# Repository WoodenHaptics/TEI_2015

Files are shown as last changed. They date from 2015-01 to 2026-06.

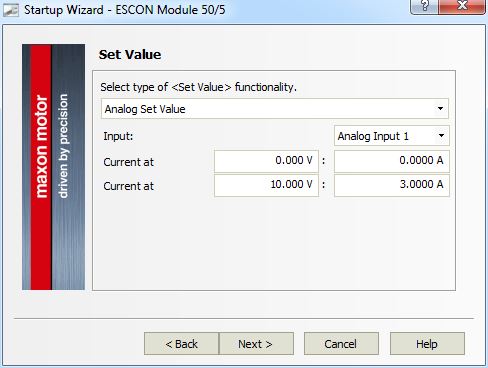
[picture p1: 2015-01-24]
Electronics/Escon-config/07.JPG

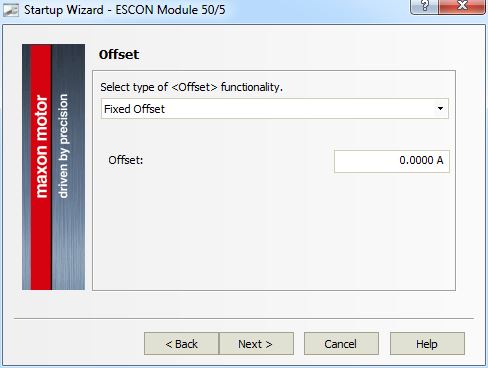
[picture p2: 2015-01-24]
Electronics/Escon-config/08.JPG

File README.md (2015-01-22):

# TEI_2015

Welcome! On this repository you will find the information you need to start fabricating your own grounded spatial haptic device based on our default open source design. This site is essentially the companion to our TEI2015 conference paper WoodenHaptics: A Starting Kit for Crafting Force-Reflecting Spatial Haptic Devices. We hope you want to share our joy of crafting haptic devices!

more information on this device and its construction in our website:
www.woodenhaptics.org

Please start with reading the website and the research paper found on the website.

The license for this whole project is CC-BY-SA 4.0 if nothing else mentioned. 
The CHAI3D extension software is BSD-licensed like its parent project. 
Are you interesed in other licensing agreements or like to distribute the kit, email jofo02 at kth.se

/ Jonas, Mike and Jordi - January 17th 2015

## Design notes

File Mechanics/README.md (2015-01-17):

  This is the source drawings for the default design of the WoodenHaptics starting kit. 
  You have to have SolidWorks to edit the files, but you also have exported drawings/cutout sheets
  for laser-cutting in the lasercut_drawings/ folder. 

  /Jonas Forsslund Jan 17th 2015

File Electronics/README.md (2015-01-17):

# Main_board_EAGLE_v_0_1

Eagle files for the main board version 0.1

This is the first version of the wooden haptics driver. This bord will accept 3 motors up to 3Amps each and 3 decoders. It has been designed to host ESCON motor drivers:

http://www.maxonmotor.com/maxon/view/product/control/4-Q-Servokontroller/438725

The same ESCON sockets can be used to connect any other DC motor driver if conencting to the propper pin connectors (PWR, motor out and PWM)

THis board can be used with and external DAQ (using the extension board) board or a mBed M3 Cortex:

https://www.sparkfun.com/products/9564

The elctronics are powerd up over USB but in order to power the motors it requires an external power supply 12v-48v, depending on the motors used.

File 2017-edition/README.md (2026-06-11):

# WoodenHaptics — 2017 Edition (notes & version history after 2015)

**Status: never formally released.** The original public release is the *Version 1.0 — TEI 2015 Edition* (Maxon RE40 motors). During 2016–2017 the kit was revised toward smaller motors and a few other improvements, but the changes were never compiled into a packaged release. This folder is a retroactive attempt to gather what exists so a proper "2017 Edition" can be assembled.

Dates below were verified from the embedded file metadata (Adobe XMP `CreateDate`/`ModifyDate`), the two bills of materials, and the 17 Jan 2017 mailing-list announcement (quoted below). Items marked *(recollection)* are from memory and should be double-checked before release.

---

## Timeline

| When | What | Source |
|---|---|---|
| Jan–Jun 2015 | **Version 1.0 (TEI 2015 Edition).** SolidWorks CAD (`Mechanics/`), DXF export (`lasercut_drawings/dxf/`), Illustrator laser files, BOM v1.0. Motor: **Maxon RE40 (Ø40 mm, 148877)**. | repo, `lasercut_drawings/README.md` (Jan 5 2015), BOM v1.0 |
| 2015-06 / 2015-10 | Illustrator laser sheets prepared from the DXFs on cutlasercut.com templates and verified for cutting. `body_a` last tweaked Oct 2015. | XMP dates, `illustrator/README.md` (Jun 2 2016) |
| **2016-10-07** | Laser-cut order: the four `Birch_Plywood_6mm_600mmx600mm_*_updated.ai` sheets **plus a separate `kirimoto-inkskape-body-c-a4.svg`** (an Inkscape A4 sheet for an experimental new *body c* / arm). *(order record)* | order info |
| **2017-01-17** | Mailing-list announcement of the updated kit (full text below): red ball handle, **smaller 30 mm motors (Maxon RE30)**, 19.5 V supply (laptop chargers), beta USB, new *body c* on Onshape, PCB v0.4, assembly videos. | email |
| **2017-05-09** | New arm brought into Illustrator: `new_body_c.ai` (exported via a **Mac**) and the combined `…body_b_and_c_updated_2017.ai/.pdf` (the lighter arm — larger triangular lightening cut-outs). | XMP dates |
| **2017-05-11** | Re-nested onto 500 × 450 mm sheets: `500x450_6mm_4_och_en_halv_skivor.ai` (+ `_uppdaterad.pdf`). | XMP dates |
| **2017-05-15** | **`Birch_Plywood_6mm_A2_four_sheets.pdf`** — final re-nest onto four A2 sheets; this is the file that was **actually ordered / cut** on this date. BOM **v1.1 "with 30 mm motors and USB"**. | XMP dates, order info, BOM v1.1 |

---

## What changed vs. the 2015 (RE40) edition

### Mechanics — RE40 → RE30
The structural design did **not** change. Verified findings:

- **Motor mount is shared.** The motor bolts to the wood with **M3 screws on a Ø22 bolt circle**, and **both RE40 and RE30 use that pattern** — so no plate needed to be re-drawn. (BOM v1.0 already lists 40 / 30 / 25 mm Maxon motors as interchangeable alternatives with the same `M3x10` screws.) The `base` / `body_a` / `body_b` laser geometry is unchanged 2015 geometry.
- **Only the arm (`body c`) was re-drawn**, to lighten it (lower inertia for the smaller motors) — `new_body_c.ai` / `…body_b_and_c_updated_2017`.

The practical RE40 → RE30 conversion is therefore just:

1. **Coupler:** `CPL25-6-10` → **`CPL12-4-5`** (RE30 has a 5 mm shaft; the new coupler is also shorter).
2. **Remove one wooden lamination** from the motor-holder stack to take up the shorter coupler/motor length. *(recollection — the motor holder is a laminated plate stack; using one layer fewer of an existing part, no new geometry.)*
3. **Motor:** `148877` (40 mm) → **`310009`** (30 mm), with 500 CPR encoder.
4. Use the **lightened arm** (`body c`).

### Electronics / system (from the 2017 announcement)
- **Red ball handle** (kitchen-drawer knob) for clearer affordance.
- **19.5 V** supply so a standard laptop charger works (e.g. Innergie PowerGear 90) — replaces the 48 V supply.
- **USB support** (beta at the time).
- **PCB v0.4.**
- Code on the `experimental` branch of the GitHub repo; assembly videos at <http://woodenhaptics.org/build.html>.

---

## Contents of this folder

```
2017-edition/
├── README.md                     ← this file
├── bom/
│   └── WoodenHaptics Bill of Materials - 2017 Edition (Ver 1.1 with 30mm motors and USB).csv
└── lasercut/
    ├── Birch_Plywood_6mm_A2_four_sheets.pdf                         ← THE production cut file (A2 ×4, 15 May 2017)
    ├── new_body_c.ai                                                ← lightened arm, exported from Onshape (Mac)
    ├── Birch Plywood_6mm_600mmx600mm_body_b_and_c_updated_2017.ai   ← combined new-arm sheet (600×600 master)
    ├── Birch Plywood_6mm_600mmx600mm_body_b_and_c_updated_2017.pdf
    ├── 500x450_6mm_4_och_en_halv_skivor.ai / _uppdaterad.pdf        ← intermediate 500×450 re-nest (11 May 2017)
    ├── Birch Plywood_6mm_600mmx600mm_base_1_of_2_updated.pdf        ← unchanged 2015 geometry (RE40 = RE30)
    ├── Birch Plywood_6mm_600mmx600mm_base_2_of_2_updated.pdf        ← unchanged 2015 geometry
    └── Birch Plywood_6mm_600mmx600mm_body_a_updated.pdf             ← unchanged 2015 geometry
```

All sheets: **6 mm birch plywood**, red (RGB 255,0,0) = cut-through, black = engrave ~1.5–2.5 mm (same conventions as `Mechanics/lasercut_drawings/`).

**If you only cut one thing, cut `Birch_Plywood_6mm_A2_four_sheets.pdf`** — it is the complete, as-built four-sheet layout (incl. the lightened arm), sized for an A2 (594 × 420 mm) laser bed.

---

## Provenance & gaps (important before a release)

- **The parametric CAD for the new arm is NOT in this repo.** It was authored in **Onshape**:
  <https://cad.onshape.com/documents/3a7c6140b3b524fe2e399f10/w/c1ea1269244ce72f85bc9402/e/6f0b243d8c0c198195d363ae>
  Locally the arm survives only as **flat laser vectors** (`new_body_c.ai`, and inside the A2 PDF). The original Inkscape source `kirimoto-inkskape-body-c-a4.svg` could not be found on any local disk.
- The RE40 parametric CAD is complete in `../Mechanics/` (SolidWorks). To make the RE30 arm editable again, either re-export from Onshape, or trace/convert `new_body_c.ai` → DXF/SVG and re-integrate.
- These 2017 laser files previously lived only in a loose `Woody-May-2017` working folder, not under version control — copied here so they are not lost.

## TODO toward a packaged 2017 Edition
- [ ] Recover or re-create editable arm CAD (Onshape export, or convert `new_body_c.ai`).
- [ ] Confirm the "remove one lamination" step and document the motor-holder stack-up for RE30 (drawing or photo).
- [ ] Add the RE30 coupler (`CPL12-4-5`) and red ball handle to a parts drawing / BOM cross-check.
- [ ] Capture the electronics changes (PCB v0.4, 19.5 V, USB) from the `experimental` branch into this edition.
- [ ] Decide whether this supersedes or sits alongside the TEI 2015 Edition, and tag a release.

---

### Appendix — 17 Jan 2017 mailing-list announcement (verbatim)

> I have been working on updating woodenhaptics kit in an attempt to make it more complete and slightly reduce cost. I propose the following changes:
> * Red ball handle (kitchen drawer knob) improves affordance i.e. makes it clear where to hold
> * Smaller motors (30 mm, Maxon RE30) are cheaper and lighter which lowers inertia.
> * Switching to 19.5V power supply so we can use standard laptop chargers, I have successfully used the Innergie Powergear 90
> * USB support working (but still beta)
>
> CAD models for new body c (arm) can be found on onshape (the collaborative, free-to-use cad software I use now)
> https://cad.onshape.com/documents/3a7c6140b3b524fe2e399f10/w/c1ea1269244ce72f85bc9402/e/6f0b243d8c0c198195d363ae
>
> Code for mbed and computer side is shared on the experimental-branch of the github. […] Updated PCB:s are also there (version 0.4).
>
> I have also made some assembly instruction videos covering the whole process […] http://woodenhaptics.org/build.html
>
> Jonas

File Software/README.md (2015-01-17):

<pre>
WoodenHaptics extension to Chai3D 3.0.0
   
Written by Jonas Forsslund, KTH, 2014-12-08

Chai3D is a minimalistic API for haptic applications. Website is www.chai3d.org
but the latest and greatest is found on cs277.stanford.edu. You need 
that EXACT version for this patch to work:

http://web.stanford.edu/class/cs277/resources/downloads/chai3d-3.0.0-Makefiles.tar.gz
(59930012 bytes))

Unzip the contents of our zip-file's subfolder into your Chai3D folder
   
then run "make". 

It will overwrite these files:

    Makefile.common.lin

    CHapticDeviceHandler.cpp
    CGenericHapticDevice.h

Note: To make sense of this you (currently) need to have a
Sensoray S826 DAQ PCIe card in your computer. You
also need to install the kernel module for that card.

That driver is provided as source in /external/s826

please read the readme.txt in that folder for instructions.

This patch is licensed under: BSD

Good luck and have fun!
   /Jonas (jofo02@kth.se)

</pre>

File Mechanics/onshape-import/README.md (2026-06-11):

# Onshape import bundle + verification

Artifacts for importing the SolidWorks `Mechanics/` model into
[Onshape](https://cad.onshape.com), and screenshots confirming it worked.

## `woodenhaptics.zip`
A **flat** archive of every SolidWorks part/assembly in `Mechanics/`
(`.SLDPRT` / `.SLDASM` / `.SLDDRW`), **excluding** `lasercut_drawings/`.

Onshape's SolidWorks importer requires that the zip contain **no folders** and
that its **filename matches the root assembly** — here `woodenhaptics.SLDASM`.
Regenerate from `Mechanics/` with:

```sh
cd Mechanics
find . -path ./lasercut_drawings -prune -o \
  -type f \( -name '*.SLDPRT' -o -name '*.SLDASM' -o -name '*.SLDDRW' \) -print |
  while read f; do zip -jq ../woodenhaptics.zip "$f"; done
```

(108 files; the part/assembly basenames are unique, so flattening is collision-free.)

## `screenshots/`
The bundle imported cleanly into Onshape. Each shot highlights one subassembly
(yellow) — this is also the rigid-body breakdown used by the FreeCAD migration
(`../../freecad-migration-plan.md`):

| File | Shows |
|---|---|
| `tei2015-woody.png` | full assembly (import tree on the left) |
| `tei2015-woody-base.png` | `base` — fixed to world (frame N) |
| `tei2015-woody-a.png` | `body_a` — θa, rotates on base |
| `tei2015-woody-b.png` | `body_b` — θb |
| `tei2015-woody-c.png` | `body_c` — driven by the four-bar |
| `tei2015-woody-c-prim.png` | `body_c_prim` — θc, the parallelogram link |

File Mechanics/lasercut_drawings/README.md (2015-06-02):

  Please note the following for laser-cutting the parts.

  - All sheets are 6 mm, preferably birch plywood
  - The source drawing(s) in .SLDDRW for each body is found in respective part's folder
  - These files are exported to .dxf files in the lasercut_drawing/dxf/ folder
  - If you alter the parts of a body, the .DWG will be updated when you load them, but
    not necessarily any exported files. So make sure to do the export (save as...) as well.
  
  - You can use the dxf directly if:
    * Your laser-cutter can handle up to A2 sheets (594 x 420 mm)
    * You make sure the laser-cutter cuts in the middle of the lines, or change
      the thickness to be as thin as is required to do so (for VLS-4.60 you set it to ~0.001 mm)
    * The BLACK AREAS should be ENGRAVED to 1.5-2.5 mm, instead of cut. Be careful to 
      set the edges of those areas to be cut through OR not cut through depending on location.
  
  - Otherwise, we reccommend:
    * Using Adobe Illustrator; "place" the .DXF file(s) on a sheet suitable for your cutter.
    * You may have to place with scaling 1:1000 or 1000:1, make sure it NEVER scales to "fit"
    * Always measure an object to see it is exactly as expected
    * Change lines to be as thin as necessary (0.001 mm/pt in our case)
    * Change line colors to be what you code as "cut through" (RGB: 255,0,0 in our case)
    * Change black areas to be coded as "engraving" (see above, in our case fill with RGB: 0,0,0)

  /Jonas Forsslund Jan 5th 2015

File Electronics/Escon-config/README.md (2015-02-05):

This is screenshots from the step-by-step configuration guide in
ESCON Studio that you find under "Download" on this page:
http://www.maxonmotor.com/maxon/view/product/control/4-Q-Servokontroller/438725

Alternatively, you can "download" the config-file.edc to the escon using ESCON Studio.

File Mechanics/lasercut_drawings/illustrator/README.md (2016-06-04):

  Please note the following for laser-cutting the parts.

  These files are prepared using the cutlasercut.com template .ai files 
  and then by "place" the .dxf files after scaling (see image
  import-from-dxf-settings.png for how this is done). 

  These updated files are tested for cutting by cutlasercut.com 
  just tell them to use 6.0 mm (or slightly less) plywood and cut
  as straight down as possible.

  /Jonas Forsslund June 2nd 2016

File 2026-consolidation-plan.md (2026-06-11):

# WoodenHaptics — 2026 Consolidation Plan

A handoff/planning doc for gathering everything WoodenHaptics into a single,
canonical 2026 repository. Written so the work can be picked up from any
computer — **everything referenced here is committed and pushed; the local
working copy can be dropped.**

Status: **draft / basis for discussion.** The big open decision (which GitHub
home) is deliberately left open — see "Open decision" below.

---

## Why consolidate
The project's material is currently scattered across several repos and editions
with overlapping, partly-stale content. The paper explicitly invites the
community to build on the kit; a single front-door repo, framed from a 2026
perspective, makes that realistic. The goal is **one repo** that holds the
2015 reference design, the never-released 2017 revision, the electronics/
software, and the forward-looking FreeCAD model — clearly separated by edition,
with a top-level README that orients a newcomer.

---

## Current GitHub landscape (verified 2026-05-19)

| Repo | State | Holds | Verdict |
|---|---|---|---|
| **`WoodenHaptics/TEI_2015`** (this repo) | active, pushed today | SolidWorks `Mechanics/`, lasercut DXF/AI, BOM v1.0, the TEI 2015 paper PDF, `2017-edition/`, `freecad-migration-plan.md`, Electronics/Software/Docs | richest mechanical source; **best basis** |
| **`WoodenHaptics/woody-experimental`** | 2019, "do not use" | PCB **v0.4** (`woodenHaptics_v_0_4.brd/.sch`), `mbed-code`, `chai3d-3.0.0-woody`, `daq-direct`, `websim`, `woodenhaptics_2016ed.json`, `woodenhaptics_aluhaptics_2017-03-16.json` | **valuable** — this is the 2016/2017 electronics + code the 2017 README points to |
| **`forsslund/WoodenHaptics`** | **fork** of MobileLifeCentre, pushed **Dec 2014** | `woodenHaptics_v_0_1`, `Sensoray_DAQ`, `DAQ_Extension_Board_December`, `woddenHaptics_Egle_files` | historical v0.1 only; it's a stale fork → poor base |
| **`MobileLifeCentre/WoodenHaptics`** | upstream original, Jan 2015 | the true origin of the fork above | historical root |

**Implication:** the substance lives in `TEI_2015` (mechanics + 2017 edition)
and `woody-experimental` (electronics + code). The personal/MobileLife repos are
mostly historical v0.1 material.

---

## Open decision — which GitHub home

Three options, with trade-offs:

1. **New repo `WoodenHaptics/woodenhaptics` (org, lowercase) — recommended.**
   Clean canonical name, lives in the org so multiple maintainers and the
   `woodenhaptics.org` identity align, and no awkward fork relationship. Pull
   `TEI_2015` and `woody-experimental` content in under `editions/` and
   `electronics/`+`software/`; then **archive** the old repos with a README
   pointer. Most work, cleanest result.

2. **Continue from `forsslund/WoodenHaptics`.** It already exists and is
   personally owned, but it's a **2014 fork of MobileLifeCentre** containing only
   v0.1-era files — the fork lineage and stale content make it a weak base. Would
   need a heavy rewrite anyway. Not recommended unless you specifically want it
   under your personal account rather than the org.

3. **Keep building inside `WoodenHaptics/TEI_2015` and rename it.** Lowest
   effort — it's already the richest repo. But the name `TEI_2015` is tied to the
   paper/citation; renaming it muddies that link, and a rename leaves redirect
   baggage. Better to keep `TEI_2015` as the frozen, citable 2015 artifact.

**Recommendation:** option 1. Keep `TEI_2015` frozen as the paper's citable
snapshot; make a fresh org repo the living home. Decide org-vs-personal
(`WoodenHaptics/` vs `forsslund/`) as a governance question — the org is the
better long-term community home, but that's yours to call.

---

## Proposed structure for the new repo

```
woodenhaptics/
├── README.md                 ← 2026 framing: what it is, editions, how to start, links to paper & woodenhaptics.org
├── LICENSE.md                ← carry over (open-source/open-hardware)
├── paper/
│   └── woodenhaptics-tei-2015-paper.pdf
├── editions/
│   ├── tei-2015/             ← from TEI_2015: Mechanics/ (SolidWorks), lasercut DXF/AI, BOM v1.0
│   │   └── README.md         ← "the citable reference design; RE40 motors"
│   └── 2017/                 ← from TEI_2015/2017-edition: RE30 lasercut, BOM v1.1, the detailed timeline README
├── cad-freecad/              ← output of freecad-migration-plan.md (articulated open-source model)
├── electronics/              ← from woody-experimental: PCB v0.4 (.brd/.sch), DAQ boards
├── software/                 ← from woody-experimental: mbed-code, chai3d-3.0.0-woody, daq-direct, websim, config JSONs
├── docs/                     ← assembly notes, build videos pointer (woodenhaptics.org/build.html)
└── archive/                  ← optional: v0.1-era material from forsslund/MobileLifeCentre if worth preserving
```

Principles:
- **Editions are folders, never branches** (additive snapshots, never merged).
- One top-level README is the front door; each edition keeps its own README
  (the 2017 one is already excellent and self-documenting).
- Bring CAD source where it exists; where it doesn't (the 2017 arm, which is
  Onshape-only — see `2017-edition/README.md`), keep the link + flat vectors and
  flag the gap.

---

## Migration checklist

- [ ] **Decide the GitHub home** (open decision above).
- [ ] Create the new repo + `README.md` skeleton with the structure above.
- [ ] Import `TEI_2015` mechanical content → `editions/tei-2015/` (preserve history
      via `git subtree`/`filter-repo` if history matters, else a clean copy).
- [ ] Move `2017-edition/` → `editions/2017/`.
- [ ] Import `woody-experimental` electronics → `electronics/`, code → `software/`.
- [ ] Run the FreeCAD migration (`freecad-migration-plan.md`) → `cad-freecad/`.
- [ ] Triage `forsslund/WoodenHaptics` + `MobileLifeCentre` v0.1 → `archive/` or drop.
- [ ] Write the 2026 front-door README (framing, editions table, getting-started,
      links to paper + woodenhaptics.org).
- [ ] **Archive** `TEI_2015` and `woody-experimental` on GitHub with a README
      pointer to the new repo (keep them — `TEI_2015` is the paper's citation target).
- [ ] Cross-check BOMs (RE40 v1.0 vs RE30 v1.1) and reconcile the open TODOs in
      `2017-edition/README.md` (editable arm CAD, motor-holder lamination, coupler,
      handle, electronics changes).

---

## Local working copy — what's here and what's safe to drop

After the commits accompanying this plan, **everything important is in git and
pushed.** This local checkout can be deleted.

- **Committed & pushed:** all of `2017-edition/`, `freecad-migration-plan.md`,
  the paper PDF, this plan, the Onshape import bundle + verification screenshots
  (`Mechanics/onshape-import/`), and the existing repo contents.
- **Removed (byte-identical duplicates):** two root CSVs — copies already live in
  the repo (TEI-2015 BOM at repo root, 2017 BOM under `2017-edition/bom/`).
- **External, not in any repo — don't lose:** the 2017 arm parametric CAD lives
  only on Onshape (link in `2017-edition/README.md`); the original Inkscape source
  `kirimoto-inkskape-body-c-a4.svg` is already missing.

---

## Related docs
- `freecad-migration-plan.md` — the articulated open-source CAD effort that feeds
  `cad-freecad/` in the new repo.
- `2017-edition/README.md` — detailed, source-verified timeline and provenance of
  the 2017 revision, plus its own TODO toward a packaged release.

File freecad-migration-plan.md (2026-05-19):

# WoodenHaptics → FreeCAD Migration Plan

## Goal
Publish an articulated FreeCAD model of the reference design so the community can open, inspect, and modify the device without proprietary software. End-effector point P can be moved by dragging; the RRR linkage and the C/C' four-bar respond correctly.

## Scope
**In:** Geometry of all parts, subassembly grouping, three revolute DOFs (θa, θb, θc), parallelogram closure, gravity-correct orientation.
**Out:** Motor→body cable ratios, cable rope geometry as a kinematic element, lasercut drawings, electronics box, software/firmware, FEA.

## Subassembly mapping
Each Mechanics/ subfolder becomes one FreeCAD document. Parts inside are rigidly fixed (no internal joints — treat each subassembly as one solid body).

| Folder | FreeCAD file | Role |
|---|---|---|
| `base/` | `base.FCStd` | Fixed to world (frame N) |
| `body_a/` | `body_a.FCStd` | Rotates θa about vertical axis on base |
| `body_b/` | `body_b.FCStd` | Rotates θb about horizontal axis on body_a |
| `body_c_prim/` | `body_c_prim.FCStd` | Rotates θc about horizontal axis on body_a |
| `body_c/` | `body_c.FCStd` | Driven via four-bar (parallel to body_b) |
| `other/` (RE40) | reuse as needed | Visual only, place inside relevant subassembly |
| top level | `woodenhaptics.FCStd` | Links the five subassemblies + joints |

## Migration steps

**1. Export from Onshape (one-time)**
Once the Onshape import lands (using the zip we built), export each subassembly separately as STEP AP242:
- `base.step`, `body_a.step`, `body_b.step`, `body_c.step`, `body_c_prim.step`
- Plus `woodenhaptics_full.step` as a sanity reference for poses.

**2. Build subassembly documents**
For each STEP:
- Open in FreeCAD → save as `.FCStd`
- Verify it imports as a single Compound or as a set of solids in their assembled positions
- If multiple solids: group under one `App::Part` container so the whole subassembly behaves as one rigid body in the top-level assembly
- No internal joints needed

**3. Build top-level assembly (`woodenhaptics.FCStd`)**
- New document, Assembly workbench
- Insert each subassembly as a linked document (File → Link)
- Ground `base` (fixed joint to origin)
- Add joints (see below)

**4. Define joints**

| Joint | Type | Between | Axis |
|---|---|---|---|
| J1 (θa) | Revolute | base ↔ body_a | Vertical (Z in N frame) through the body_a turntable center |
| J2 (θb) | Revolute | body_a ↔ body_b | Horizontal, through body_b's shaft bearings on body_a |
| J3 (θc) | Revolute | body_a ↔ body_c_prim | Horizontal, parallel to J2, through body_c_prim's shaft |
| J4 | Revolute | body_b ↔ body_c | Horizontal, at the far end of body_b |
| J5 | Revolute | body_c_prim ↔ body_c | Horizontal, at the far end of body_c_prim (closes the four-bar) |

J4 + J5 close the loop. The OndselSolver should resolve this as a single DOF along θc once θa and θb are fixed. If it struggles to converge, pin θc as the driver on J3 and let J5 float (or vice versa) — pick whichever solves cleanly.

**5. Verify articulation**
- Drag body_a around vertical axis → whole arm sweeps (θa works)
- Drag body_b → body_c stays parallel to it as the four-bar pivots (θb works, parallelogram correct)
- Drag body_c_prim → body_c translates parallel to body_b (θc works)
- Confirm end-point P traces a workspace consistent with eq. (1) in the paper

**6. Polish for publication**
- Set materials/colors (plywood color on structural parts, dark on motors/bearings)
- Add a simple `README.md` explaining the joint structure and noting what is *not* modelled (cable ratios)
- Save with FreeCAD 1.0+ format; document the minimum FreeCAD version in README

## Deliverables
- `freecad/` directory in the repo with the six `.FCStd` files
- `freecad/README.md` covering versions, how to open, known limitations
- An exported `woodenhaptics_articulated.step` for users who want to consume it in other tools

## Risks / open questions
- **Four-bar convergence**: if OndselSolver chokes on the closed loop, fallback is to omit J5 and just animate body_c manually parallel to body_b via a single expression (`body_c.Placement = body_b.Placement` with offset). Less elegant but visually identical.
- **STEP per-subassembly vs. one big STEP**: exporting subassemblies separately preserves the grouping we want; exporting one big STEP and re-splitting in FreeCAD is more work. Go with separate exports if Onshape allows it cleanly.
- **Motor placement**: paper says motors B and C mount on body_a. If they're geometrically inside `body_a/` already in your SLDASM, no extra work. If they live in `other/`, decide which subassembly they belong to before exporting.

## Suggested order of work
1. Get the Onshape import working (already in motion)
2. Export the five subassembly STEPs
3. Build `base.FCStd` and `body_a.FCStd`, prove J1 works in a minimal two-body assembly
4. Add body_b + J2, verify
5. Add body_c_prim + J3
6. Close the loop with body_c + J4 + J5
7. Polish, write README, commit

Roughly a half-day of focused work if the STEP imports cleanly; a full day if the four-bar needs coaxing.

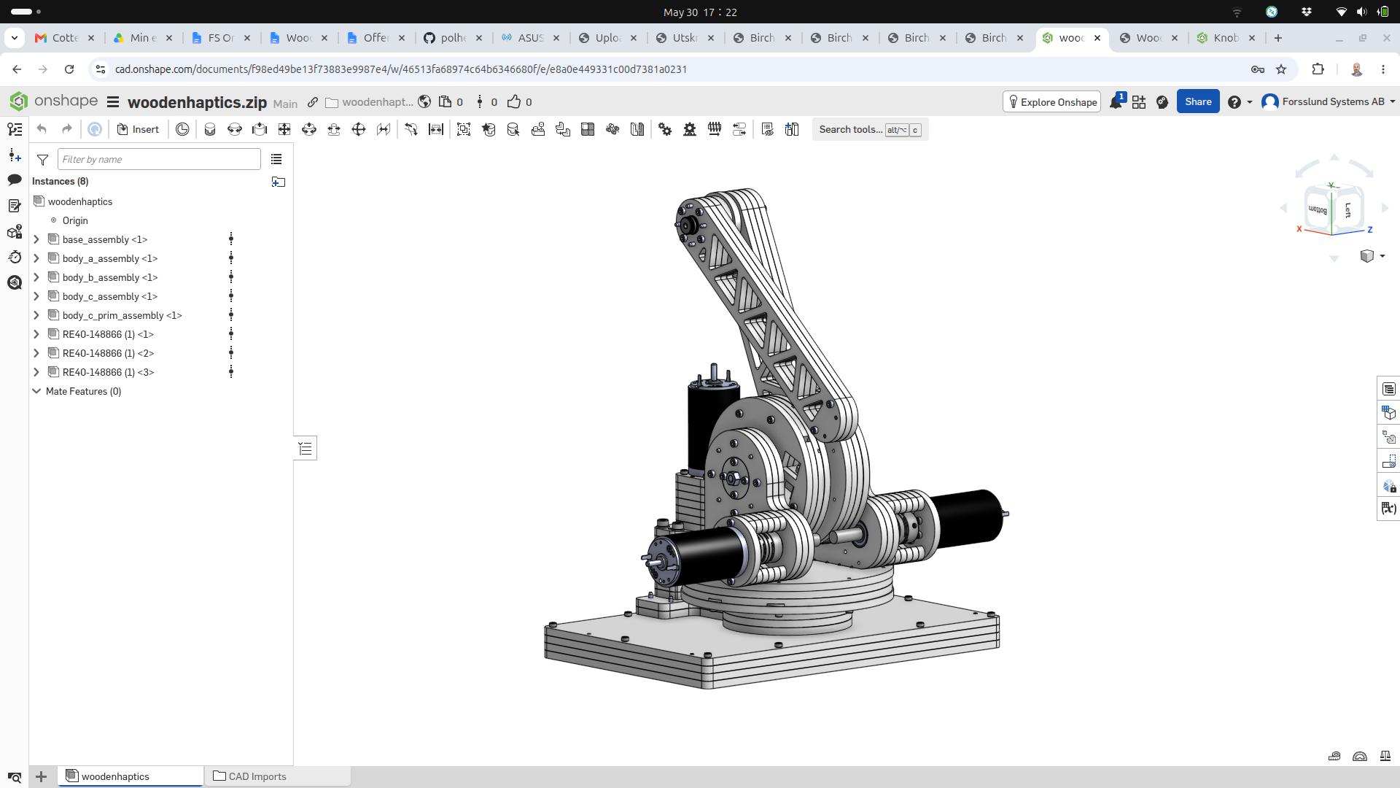
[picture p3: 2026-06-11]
Mechanics/onshape-import/screenshots/tei2015-woody.png

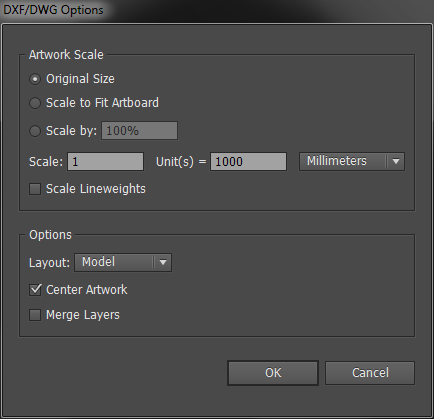
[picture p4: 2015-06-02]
Mechanics/lasercut_drawings/illustrator/import-from-dxf-settings.png

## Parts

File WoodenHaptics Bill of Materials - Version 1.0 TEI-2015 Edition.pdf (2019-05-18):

Lowest WoodenHaptics.org Bill of Materials and Recommended Equipment | Estimated part cost w/o motor & enc.: | €962.23 | €962.23
Estimated motor & encoder cost: | €1,420.78 | €1,420.78 We will try to reduce the number of distributors to reduce complexity | Estimated PC connection cost: | €811.29 | €51.61 Maxon, Farnell and Misumi is easy to access globally | Estimated required tools cost: | €196.95 | €0.00 Other distributors might be tricky in some parts of the world | Estimated total* part cost for kit: | €3,391.25 | €2,434.62

Let us know your experience in the forum of woodenhaptics.org

*) No labour cost included, i.e. for laser-cutting or soldering. | 1 EUR in SEK | kr9.45
Largest costs are in the motors, drivers and PCIe card that could | 1 EUR in USD | $1.19
be re-used in several projects if you so wish. Required tools | 1 EUR in CHF | CHF1.03

(except laser-cutter and soldering tools) are included.

Suggested distributor (Europe) part number | Estimated Unit Cost € Alter- native Our Name | quantity Maxon Farnell | Misumi | Elektrokit Tecni-cable Other Distributor | Full name | Notes | Sum Cost
€0.00 MECHANICS | €0.00

€0.00

Raw Material | | | | | | | | | | | | | | | | | | | | | €0.00
6 mm birch plywood A2 sheet (594 x 420 mm) (alternatives possible) | 5 | Local / cutlasercut.com | €5.29 | €26.46
| | | | | | | | | | | | | | | | | | | | | €0.00
Construction Hardware: Base | €0.00 M3x10 (for motor) | 6 | CB3-10 | €0.09 | €0.54 M3x35 | 6 | CB3-35 | €0.12 | €0.72 M3x50 | 4 | CB3-50 | €0.24 | €0.96 M5x90 | 6 | CB5-90 | €0.30 | €1.80 M3x22 | 10 | CB3-22 | €0.10 | €1.00
6x10x1 washer | 6 | WSSB10-6-1 | €1.05 | €6.30
10x55x4x5 capstan (10x55 shaft (RDOF10-55) ok if 10mm coupler) | | 1 | SFRMHP10-55-F5-P4 | €7.36 | €7.36
10x22x6 bearing | 2 | SB6900ZZ | €5.60 | €11.20
Flexible Coupler that fits motor shaft diameter and 4 (10) mm capstan | | 1 | CPL25-6-10 | €28.80 | €28.80
ALT For smaller motor, use CPL12-3-4 or CPL12-4-5 | | 0
3x20 dowel pin | 4 | MS3-20 | €0.08 | €0.32
3x40 dowel pin | 7 | MS3-40 | €0.20 | €1.40
3x60 dowel pin (Substitute with MS3-40) | | 5 | MS3-40 | €0.20 | €1.00
| | | | | €0.00
Construction Hardware: Body A | €0.00 M3x10 (for motor) | 12 | CB3-10 | €0.09 | €1.08
8x22x7 bearing | 2 | B608ZZ | €1.80 | €3.60
10x22x6 bearing | 4 | SB6900ZZ | €5.60 | €22.40 M3x22 | 7 | CB3-22 | €0.10 | €0.70 M3x18 | 16 | CB3-18 | €0.09 | €1.44 M3x45 | 6 | CB3-45 | €0.17 | €1.02 M6/1.0 nut | 1 | LBNR6 | €0.32 | €0.32 M4x45 full thread (thread M4/0.75) | 1 | ACB4-45 | €0.35 | €0.35 M4/0.75 nut | 1 | LBNR4 | €0.28 | €0.28
8x60 Shoulder bolt | 1 | MSB8-60 | €0.80 | €0.80
8x110 Shoulder bolt (thread M6/1.0) | 1 | MSB8-110 | €1.00 | €1.00
8x05 Belleville (spring) washer | 1 | SSRBW8 | €1.05 | €1.05
8x14x05 shim | 6 | CIMR8-14-0.5 | €0.50 | €3.00
Flexible Coupler (25x10x6 or 16x6x5) | 2 | CPL25-6-10 | €28.80 | €57.60
10x55x4x5 capstan (10x55 shaft (RDOF10-55) ok if 10mm coupler) | 2 | SFRMHP10-55-F5-P4 | €7.36 | €14.72

€0.00

Construction Hardware: Body B | €0.00
8x14x05 shim | 1 | CIMR8-14-0.5 | €0.42 | €0.42
8x05 Belleville (spring) washer | 1 | SSRBW8 | €1.05 | €1.05
3x25 pin | 9 | MS3-25 | €0.20 | €1.80 M3x22 | 11 | CB3-22 | €0.10 | €1.10
8x22x7 bearing | 4 | B608ZZ | €1.80 M4x45 full thread (thread M4/0.75) | 1 | ACB4-45 | €0.35 | €0.35 M4/0.75 nut | 1 | LBNR4 | €0.28 | €0.28

€0.00

Construction Hardware: Body C | €0.00 M3x30 | 4 | CB3-30 | €0.12 | €0.48 M3x18 | 2 | CB3-18 | €0.09 | €0.18
3x20 dowel pin | 2 | MS3-20 | €0.08 | €0.16
3x35 dowel pin (3x30 preferred) | 4 | MS3-35 | €0.20 | €0.80
8x60 shoulder bolt | 1 | MSB8-60 | €0.80 | €0.80

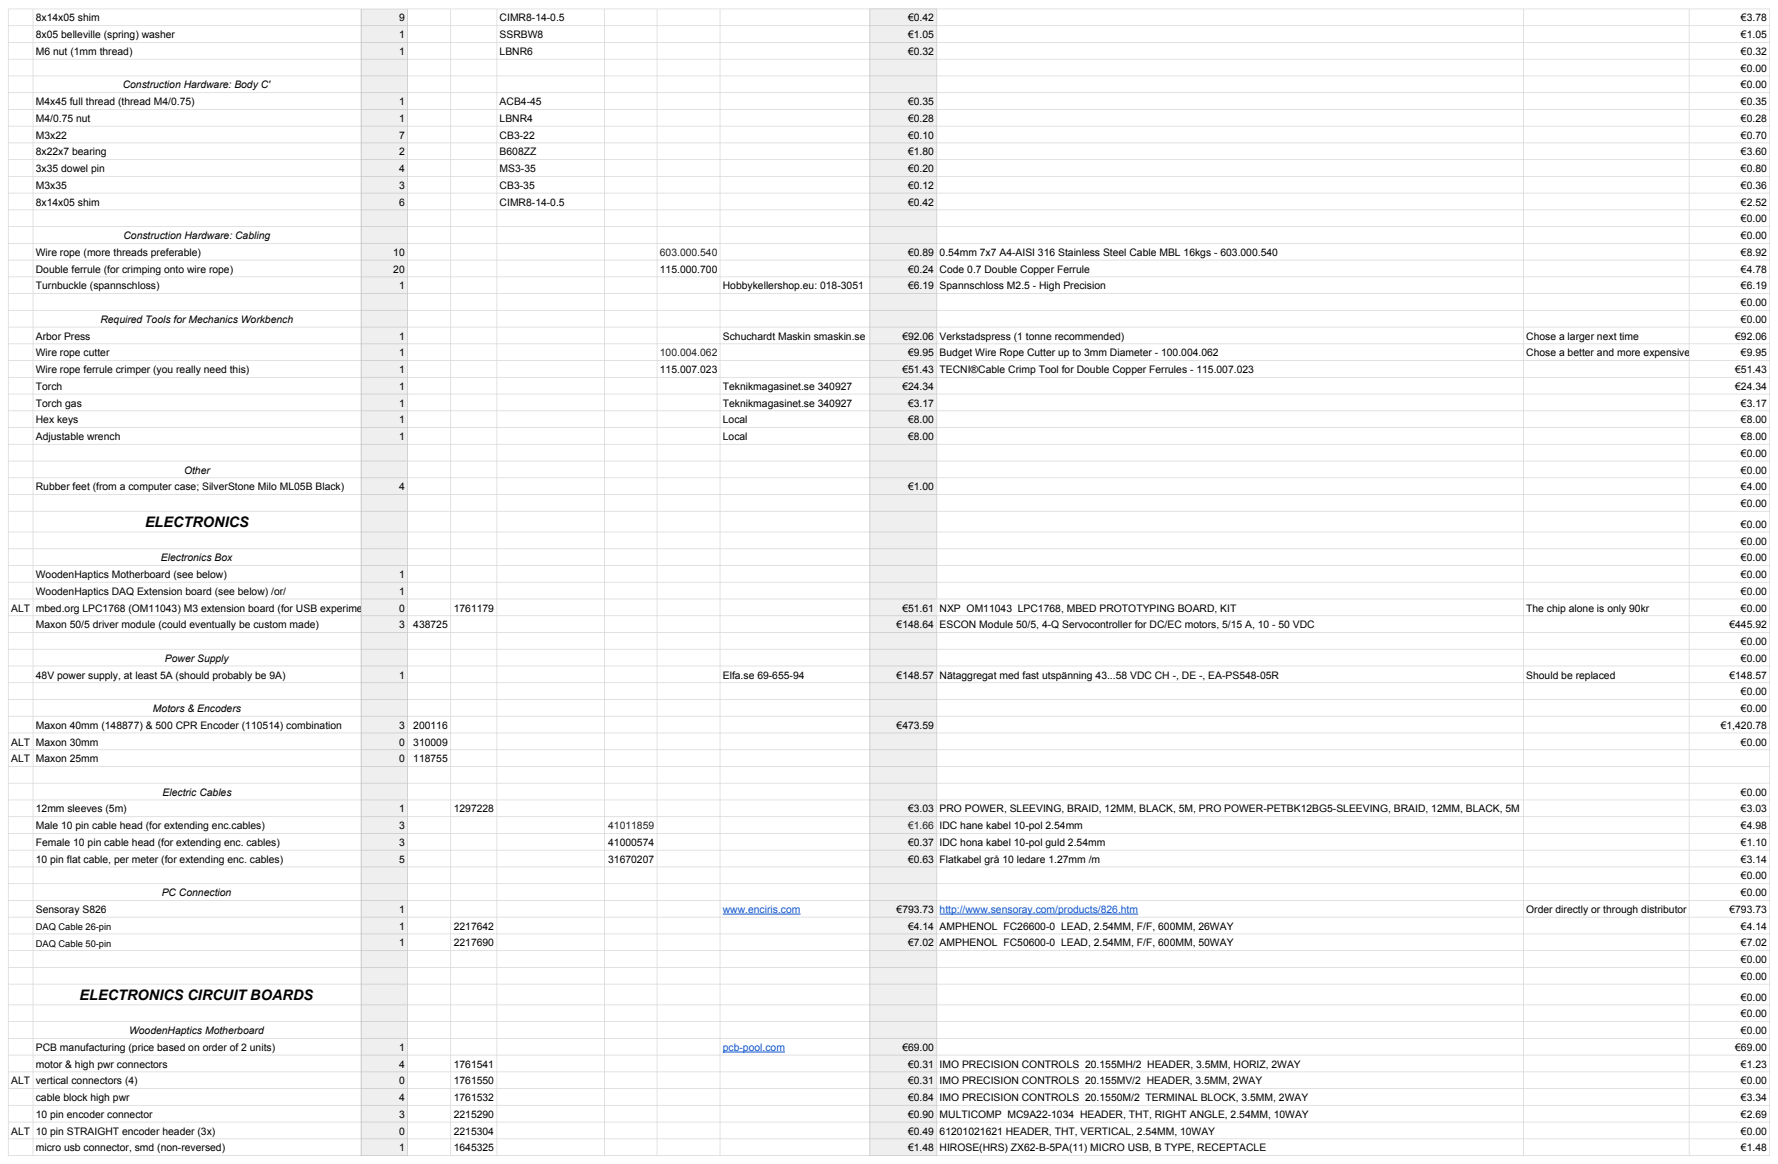
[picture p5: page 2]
8x14x05 shim; CIMR8-14-0.5; 8x05 belleville (spring) washer; SSRBW8; €1.05 M6 nut (1mm thread); LBNR6; Construction Hardware: Body C'; €0.00 M4x45 full thread (thread M4/0.75); ACB4-45; €0.35 M4/0.75 nut; LBNR4; 8x22x7 bearing; 3x35 dowel pin; Construction Hardware: Cabling; €0.00 Wire rope (more threads preferable); 0.54mm 7x7 A4-AISI 316 Stainless Steel Cable MBL 16kgs - 603.000.540; Double ferrule (for crimping onto wire rope); Code 0.7 Double Copper Ferrule; Turnbuckle (spannschloss)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

DAQ Cable 26-pin DAQ Cable 50-pin | 1 1 | 2217642 2217690 | €4.14 €7.02 | AMPHENOL FC26600-0 LEAD, 2.54MM, F/F, 600MM, 26WAY €4.14 AMPHENOL FC50600-0 LEAD, 2.54MM, F/F, 600MM, 50WAY €7.02

PCB manufacturing (price based on order of 2 units) | 1 4 | 1761541 pcb-pool.com | €69.00 €0.31 | €0.00 €0.00 ELECTRONICS CIRCUIT BOARDS €0.00 €0.00 WoodenHaptics Motherboard €0.00 IMO PRECISION CONTROLS 20.155MH/2 HEADER, 3.5MM, HORIZ, 2WAY €69.00 motor & high pwr connectors €1.23

ALT | vertical connectors (4) | 0 | 1761550 | €0.31 | IMO PRECISION CONTROLS 20.155MV/2 HEADER, 3.5MM, 2WAY €0.00
cable block high pwr 10 pin encoder connector | | 4 3 | 1761532 2215290 | €0.84 €0.90 | IMO PRECISION CONTROLS 20.1550M/2 TERMINAL BLOCK, 3.5MM, 2WAY €3.34 MULTICOMP MC9A22-1034 HEADER, THT, RIGHT ANGLE, 2.54MM, 10WAY €2.69

20 pin socket (to ext. board) | 2 | 1593469 | €1.76 | MULTICOMP 2212S-20SG-85 SOCKET, PCB, 1 ROW, 20WAY | €3.51
4 pin socket (to ext. board) | 1 | 1593460 | €0.39 | MULTICOMP 2212S-04SG-85 SOCKET, PCB, 1 ROW, 4WAY | €0.39
18 pin (2x9) escon socket | 3 | 1668305 | €3.66 | SAMTEC SSQ-109-01-G-D RECEPTACLE, 2.54MM, DUAL, 18WAY | €10.97
12 pin escon socket (1 pin discarded) | 3 | 1593465 | €0.16 | MULTICOMP 2212S-12SG-85 SOCKET, PCB, 1 ROW, 12WAY | €0.48
Encoder driver | 3 | 1103045 | €1.02 | TEXAS INSTRUMENTS AM26LS32ACD IC, DIFF LINE RECEIVER QUAD, 26LS32 | €3.06
€0.00 WoodenHaptics DAQ Extension Board | €0.00
PCB manufacturing (price based on order of 6 units) | 1 | pcb-pool.com | €15.70 | €15.70
50 pin daq connector | 1 | 2215272 | €1.93 | AMPHENOL T816150A1S102CEU HEADER, L/LATCH, STR, 2.54MM, 50WAY | Should be replaced with low profile | €1.93
26 pin daq connector | 1 | 2217535 | €1.71 | AMPHENOL T816126A1S102CEU HEADER, L/LATCH, STR, 2.54MM, 26WAY | Should be replaced with low profile | €1.71
44 pins (50) ext. board | 1 | 3418388 | €2.76 | TE CONNECTIVITY / AMP 5-826629-0 HEADER, 1ROW, 50WAY | €2.76

€0.00

Box Enclosure Mounting | €0.00
Distance screws | 4 | 1466725 | €0.30 | ETTINGER SPACER, M3X, 5-VZK ETTINGER-05.13.051-SPACER, M3X, 5-VZK | €1.21 M3x6 screws (preferably M3x4 screws that comes with computers) | 4 | 1419986 | €0.02 | DURATOOL-M36 PRSTMCZ100--SCREW, STEEL, BZP, 6MM, M3, PK100 | €0.09 M3 washers | 4 | 1377536 | €0.01 | DURATOOL M3 BRASS FULL WASHER WASHER, FULL, BRASS, M3 | €0.04

€0.00

Recommended Equipment for Electronics Workbench | | | | | | | | | | €0.00
Proper soldering station | 0 | 1447700 | €375.13 | WELLER WD 1000T (EU) SOLDERING STATION, 80W, 50DEG-450DEG, EU | €0.00
Proper oscilloscope (not really needed, for testing only) | 0 | 2191868 | €823.17 | TEKTRONIX DPO2002B OSCILLOSCOPE, 2CH, 70MHZ, 1GSPS | €0.00
Solder cleaner | 0 | 1792731 | €4.86 | WELLER CLEANER, WOOL, BRASS, WDC, PK2 WELLER-T0051384099-CLEANER, WOOL, BRASS, WDC, PK2 | €0.00
Solder activator | 0 | 873895 | €8.76 | WELLER TIP ACTIVATOR, LOW TEMP, 25G WELLER-TIP ACTIVATOR-TIP ACTIVATOR, LOW TEMP, 25G | €0.00
Solder 1.2 mm tip | 0 | 1282099 | €4.86 | WELLER TIP, SOLDERING IRON, ROUND, BENT, 1.2MM WELLER-LTF-TIP, SOLDERING IRON, ROUND, BENT, 1.2MM | €0.00
Solder 0.5 mm tip | 0 | 1282096 | €4.97 | WELLER TIP, SOLDERING IRON, ROUND, 0.5MM WELLER-LT1SA-TIP, SOLDERING IRON, ROUND, 0.5MM | €0.00 Organizer cabinet (Sortimentskåp) | 0 | 1367091 | €21.67 | RAACO CABINET, ORGANISER, 44COMPARTMENT | €0.00
De-soldering | 0 | | | | €0.00
Tweezers | 0 | 1617218 | €81.80 | DURATOOL-D00840-TWEEZERS SET, ESD SAFE, 6PC | €0.00
Hack-cables | 0 | | | | €0.00
Thin lead | 0 | | | | €0.00
Thicker lead | 0 | | | | €0.00
Scalpel | 0 | | | | €0.00
Precision cutter | 0 | | | | €0.00
Electrostatic mat kit with wristband and earth connector | 0 | 1736631 | €110.69 | MULTICOMP 069-0007 ESD WORKSTATION KIT, BLACK 0.7X1M | €0.00
Heat gun | 0 | 2473569 | €126.24 | STEINEL HL 2020 E EURO
Heat gun accessory for (reflector) for crimp tubes | 0 | 3116797 | €15.34 | STEINEL-070519-NOZZLE, REFLECTOR, SMALL
| 0 | | | | €0.00
€0.00 COMPUTER (OPTIONAL) | €0.00
ITX Motherboard AM1 (MSI AM1I) | 0 | Komplett.se 811857 | €25.29 | MSI AM1I, Socket-AM1 mini-ITX, DDR3, 1x-PCIe-x16, GbLAN, USB3.0, VGA, DVI, HDMI | €0.00
CPU (AMD Athlon 5350 APU) | 0 | Komplett.se 809078 | €46.48 | AMD Athlon 5350 Socket-AM1, Quad Core, 2.05GHz, 2MB, 25W, 28nm, Radeon R3-series, Boxed w/fan | €0.00
PSU Small form factor | 0 | Komplett.se 802785 | €39.37 | Silverstone ST30SF 300W PSU SFX, 80 Plus Bronze, Standard, 1x 6pin PCIe, 3x SATA, 2x Molex, 1x FD | €0.00 Wireless keyboard/trackpad combo | 0 | Komplett.se 645476 | €24.55 | Logitech Wireless Touch Keyboard K400 | €0.00
Case SilverStone Milo ML05B Black | 0 | inet.se | €63.39 | SilverStone Milo ML05B Svart | €0.00
PCIe flexible riser | 0 | inet.se | €10.48 | ASRock BTCPro Kit (PCIe riser) | €0.00

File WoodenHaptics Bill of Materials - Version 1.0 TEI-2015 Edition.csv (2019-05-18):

 |  |  |  |  |  |  |  | Lowest
 | WoodenHaptics.org Bill of Materials and Recommended Equipment |  | Estimated part cost w/o motor & enc.: |  |  |  | €962.23 | €962.23
 |  |  | Estimated motor & encoder cost: |  |  |  | €1,420.78 | €1,420.78
 | We will try to reduce the number of distributors to reduce complexity |  | Estimated PC connection cost: |  |  |  | €811.29 | €51.61
 | Maxon, Farnell and Misumi is easy to access globally |  | Estimated required tools cost: |  |  |  | €196.95 | €0.00
 | Other distributors might be tricky in some parts of the world |  | Estimated total* part cost for kit: |  |  |  | €3,391.25 | €2,434.62
 | Let us know your experience in the forum of woodenhaptics.org
 | *) No labour cost included, i.e. for laser-cutting or soldering. |  | 1 EUR in SEK |  |  |  | kr9.45
 | Largest costs are in the motors, drivers and PCIe card that could |  | 1 EUR in USD |  |  |  | $1.19
 | be re-used in several projects if you so wish. Required tools |  | 1 EUR in CHF |  |  |  | CHF1.03
 | (except laser-cutter and soldering tools) are included.
 |  |  | Suggested distributor (Europe) part number |  |  |  |  |  |  | Estimated Unit Cost €
Alter- native | Our Name | quantity | Maxon | McMaster | Farnell | Misumi | Elektrokit | Tecni-cable | Other Distributor |  | Full name | Notes | Sum Cost
 |  |  |  |  |  |  |  |  |  |  |  |  | €0.00
 | MECHANICS |  |  |  |  |  |  |  |  |  |  |  | €0.00
 |  |  |  |  |  |  |  |  |  |  |  |  | €0.00
 | Raw Material |  |  |  |  |  |  |  |  |  |  |  | €0.00
 | 6 mm birch plywood A2 sheet (594 x 420 mm) (alternatives possible) | 5 |  |  |  |  |  |  | Local / cutlasercut.com | €5.29 |  |  | €26.46
 |  |  |  |  |  |  |  |  |  |  |  |  | €0.00
 | Construction Hardware: Base |  |  |  |  |  |  |  |  |  |  |  | €0.00
 | M3x10 (for motor) | 6 |  |  |  | CB3-10 |  |  |  | €0.09 |  |  | €0.54
 | M3x35 | 6 |  | 91290A135 |  | CB3-35 |  |  |  | €0.12 |  |  | €0.72
 | M3x50 | 4 |  | 91290A137 |  | CB3-50 |  |  |  | €0.24 |  |  | €0.96
 | M5x90 | 6 |  | 91290A278 |  | CB5-90 |  |  |  | €0.30 |  |  | €1.80
 | M3x22 | 10 |  | 91290A124 |  | CB3-22 |  |  |  | €0.10 |  |  | €1.00
 | 6x10x1 washer | 6 |  |  |  | WSSB10-6-1 |  |  |  | €1.05 |  |  | €6.30
 | 10x55x4x5 capstan (10x55 shaft (RDOF10-55) ok if 10mm coupler) | 1 |  |  |  | SFRMHP10-55-F5-P4 |  |  |  | €7.36 |  |  | €7.36
 | 10x22x6 bearing | 2 |  |  |  | SB6900ZZ |  |  |  | €5.60 |  |  | €11.20
 | Flexible Coupler that fits motor shaft diameter and 4 (10) mm capstan | 1 |  |  |  | CPL25-6-10 |  |  |  | €28.80 |  |  | €28.80
ALT | For smaller motor, use CPL12-3-4 or CPL12-4-5 | 0
 | 3x20 dowel pin | 4 |  |  |  | MS3-20 |  |  |  | €0.08 |  |  | €0.32
 | 3x40 dowel pin | 7 |  |  |  | MS3-40 |  |  |  | €0.20 |  |  | €1.40
 | 3x60 dowel pin (Substitute with MS3-40) | 5 |  |  |  | MS3-40 |  |  |  | €0.20 |  |  | €1.00
 |  |  |  |  |  |  |  |  |  |  |  |  | €0.00
 | Construction Hardware: Body A |  |  |  |  |  |  |  |  |  |  |  | €0.00
 | M3x10 (for motor) | 12 |  |  |  | CB3-10 |  |  |  | €0.09 |  |  | €1.08
 | 8x22x7 bearing | 2 |  |  |  | B608ZZ |  |  |  | €1.80 |  |  | €3.60
 | 10x22x6 bearing | 4 |  |  |  | SB6900ZZ |  |  |  | €5.60 |  |  | €22.40
 | M3x22 | 7 |  |  |  | CB3-22 |  |  |  | €0.10 |  |  | €0.70
 | M3x18 | 16 |  |  |  | CB3-18 |  |  |  | €0.09 |  |  | €1.44
 | M3x45 | 6 |  |  |  | CB3-45 |  |  |  | €0.17 |  |  | €1.02
 | M6/1.0 nut | 1 |  |  |  | LBNR6 |  |  |  | €0.32 |  |  | €0.32
 | M4x45 full thread (thread M4/0.75) | 1 |  |  |  | ACB4-45 |  |  |  | €0.35 |  |  | €0.35
 | M4/0.75 nut | 1 |  |  |  | LBNR4 |  |  |  | €0.28 |  |  | €0.28
 | 8x60 Shoulder bolt | 1 |  | 92981A215 |  | MSB8-60 |  |  |  | €0.80 |  |  | €0.80
 | 8x110 Shoulder bolt (thread M6/1.0) | 1 |  |  |  | MSB8-110 |  |  |  | €1.00 |  |  | €1.00
 | 8x05 Belleville (spring) washer | 1 |  | 94065K340 |  | SSRBW8 |  |  |  | €1.05 |  |  | €1.05
 | 8x14x05 shim | 6 |  | 98055A114 |  | CIMR8-14-0.5 |  |  |  | €0.50 |  |  | €3.00
 | Flexible Coupler (25x10x6 or 16x6x5) | 2 |  |  |  | CPL25-6-10 |  |  |  | €28.80 |  |  | €57.60
 | 10x55x4x5 capstan (10x55 shaft (RDOF10-55) ok if 10mm coupler) | 2 |  |  |  | SFRMHP10-55-F5-P4 |  |  |  | €7.36 |  |  | €14.72
 |  |  |  |  |  |  |  |  |  |  |  |  | €0.00
 | Construction Hardware: Body B |  |  |  |  |  |  |  |  |  |  |  | €0.00
 | 8x14x05 shim | 1 |  | 98055A114 |  | CIMR8-14-0.5 |  |  |  | €0.42 |  |  | €0.42
 | 8x05 Belleville (spring) washer | 1 |  | 94065K340 |  | SSRBW8 |  |  |  | €1.05 |  |  | €1.05
 | 3x25 pin | 9 |  |  |  | MS3-25 |  |  |  | €0.20 |  |  | €1.80
 | M3x22 | 11 |  |  |  | CB3-22 |  |  |  | €0.10 |  |  | €1.10
 | 8x22x7 bearing | 4 |  |  |  | B608ZZ |  |  |  | €1.80
 | M4x45 full thread (thread M4/0.75) | 1 |  |  |  | ACB4-45 |  |  |  | €0.35 |  |  | €0.35
 | M4/0.75 nut | 1 |  |  |  | LBNR4 |  |  |  | €0.28 |  |  | €0.28
 |  |  |  |  |  |  |  |  |  |  |  |  | €0.00
 | Construction Hardware: Body C |  |  |  |  |  |  |  |  |  |  |  | €0.00
 | M3x30 | 4 |  |  |  | CB3-30 |  |  |  | €0.12 |  |  | €0.48
 | M3x18 | 2 |  |  |  | CB3-18 |  |  |  | €0.09 |  |  | €0.18
 | 3x20 dowel pin | 2 |  |  |  | MS3-20 |  |  |  | €0.08 |  |  | €0.16
 | 3x35 dowel pin (3x30 preferred) | 4 |  |  |  | MS3-35 |  |  |  | €0.20 |  |  | €0.80
 | 8x60 shoulder bolt | 1 |  | 92981A215 |  | MSB8-60 |  |  |  | €0.80 |  |  | €0.80
 | 8x14x05 shim | 9 |  | 98055A114 |  | CIMR8-14-0.5 |  |  |  | €0.42 |  |  | €3.78
 | 8x05 belleville (spring) washer | 1 |  |  |  | SSRBW8 |  |  |  | €1.05 |  |  | €1.05
 | M6 nut (1mm thread) | 1 |  |  |  | LBNR6 |  |  |  | €0.32 |  |  | €0.32
 |  |  |  |  |  |  |  |  |  |  |  |  | €0.00
 | Construction Hardware: Body C' |  |  |  |  |  |  |  |  |  |  |  | €0.00
 | M4x45 full thread (thread M4/0.75) | 1 |  |  |  | ACB4-45 |  |  |  | €0.35 |  |  | €0.35
 | M4/0.75 nut | 1 |  |  |  | LBNR4 |  |  |  | €0.28 |  |  | €0.28
 | M3x22 | 7 |  | 91290A124 |  | CB3-22 |  |  |  | €0.10 |  |  | €0.70
 | 8x22x7 bearing | 2 |  |  |  | B608ZZ |  |  |  | €1.80 |  |  | €3.60
 | 3x35 dowel pin | 4 |  |  |  | MS3-35 |  |  |  | €0.20 |  |  | €0.80
 | M3x35 | 3 |  |  |  | CB3-35 |  |  |  | €0.12 |  |  | €0.36
 | 8x14x05 shim | 6 |  | 98055A114 |  | CIMR8-14-0.5 |  |  |  | €0.42 |  |  | €2.52
 |  |  |  |  |  |  |  |  |  |  |  |  | €0.00
 | Construction Hardware: Cabling |  |  |  |  |  |  |  |  |  |  |  | €0.00
 | Wire rope (more threads preferable) | 10 |  |  |  |  |  | 603.000.540 |  | €0.89 | 0.54mm 7x7 A4-AISI 316 Stainless Steel Cable MBL 16kgs - 603.000.540 |  | €8.92
 | Double ferrule (for crimping onto wire rope) | 20 |  |  |  |  |  | 115.000.700 |  | €0.24 | Code 0.7 Double Copper Ferrule |  | €4.78
 | Turnbuckle (spannschloss) | 1 |  |  |  |  |  |  | Hobbykellershop.eu: 018-3051 | €6.19 | Spannschloss M2.5 - High Precision |  | €6.19
 |  |  |  |  |  |  |  |  |  |  |  |  | €0.00
 | Required Tools for Mechanics Workbench |  |  |  |  |  |  |  |  |  |  |  | €0.00
 | Arbor Press | 1 |  |  |  |  |  |  | Schuchardt Maskin smaskin.se | €92.06 | Verkstadspress (1 tonne recommended) | Chose a larger next time | €92.06
 | Wire rope cutter | 1 |  |  |  |  |  | 100.004.062 |  | €9.95 | Budget Wire Rope Cutter up to 3mm Diameter - 100.004.062 | Chose a better and more expensive | €9.95
 | Wire rope ferrule crimper (you really need this) | 1 |  |  |  |  |  | 115.007.023 |  | €51.43 | TECNI®Cable Crimp Tool for Double Copper Ferrules - 115.007.023 |  | €51.43
 | Torch | 1 |  |  |  |  |  |  | Teknikmagasinet.se 340927 | €24.34 |  |  | €24.34
 | Torch gas | 1 |  |  |  |  |  |  | Teknikmagasinet.se 340927 | €3.17 |  |  | €3.17
 | Hex keys | 1 |  |  |  |  |  |  | Local | €8.00 |  |  | €8.00
 | Adjustable wrench | 1 |  |  |  |  |  |  | Local | €8.00 |  |  | €8.00
 |  |  |  |  |  |  |  |  |  |  |  |  | €0.00
 | Other |  |  |  |  |  |  |  |  |  |  |  | €0.00
 | Rubber feet (from a computer case; SilverStone Milo ML05B Black) | 4 |  |  |  |  |  |  |  | €1.00 |  |  | €4.00
 |  |  |  |  |  |  |  |  |  |  |  |  | €0.00
 | ELECTRONICS |  |  |  |  |  |  |  |  |  |  |  | €0.00
 |  |  |  |  |  |  |  |  |  |  |  |  | €0.00
 | Electronics Box |  |  |  |  |  |  |  |  |  |  |  | €0.00
 | WoodenHaptics Motherboard (see below) | 1 |  |  |  |  |  |  |  |  |  |  | €0.00
 | WoodenHaptics DAQ Extension board (see below) /or/ | 1 |  |  |  |  |  |  |  |  |  |  | €0.00
ALT | mbed.org LPC1768 (OM11043) M3 extension board (for USB experimental) | 0 |  |  | 1761179 |  |  |  |  | €51.61 | NXP OM11043 LPC1768, MBED PROTOTYPING BOARD, KIT | The chip alone is only 90kr | €0.00
 | Maxon 50/5 driver module (could eventually be custom made) | 3 | 438725 |  |  |  |  |  |  | €148.64 | ESCON Module 50/5, 4-Q Servocontroller for DC/EC motors, 5/15 A, 10 - 50 VDC |  | €445.92
 |  |  |  |  |  |  |  |  |  |  |  |  | €0.00
 | Power Supply |  |  |  |  |  |  |  |  |  |  |  | €0.00
 | 48V power supply, at least 5A (should probably be 9A) | 1 |  |  |  |  |  |  | Elfa.se 69-655-94 | €148.57 | Nätaggregat med fast utspänning 43...58 VDC CH -, DE -, EA-PS548-05R | Should be replaced | €148.57
 |  |  |  |  |  |  |  |  |  |  |  |  | €0.00
 | Motors & Encoders |  |  |  |  |  |  |  |  |  |  |  | €0.00
 | Maxon 40mm (148877) & 500 CPR Encoder (110514) combination | 3 | 200116 |  |  |  |  |  |  | €473.59 |  |  | €1,420.78
ALT | Maxon 30mm | 0 | 310009 |  |  |  |  |  |  |  |  |  | €0.00
ALT | Maxon 25mm | 0 | 118755
 | Electric Cables |  |  |  |  |  |  |  |  |  |  |  | €0.00
 | 12mm sleeves (5m) | 1 |  |  | 1297228 |  |  |  |  | €3.03 | PRO POWER, SLEEVING, BRAID, 12MM, BLACK, 5M, PRO POWER-PETBK12BG5-SLEEVING, BRAID, 12MM, BLACK, 5M |  | €3.03
 | Male 10 pin cable head (for extending enc.cables) | 3 |  |  |  |  | 41011859 |  |  | €1.66 | IDC hane kabel 10-pol 2.54mm |  | €4.98
 | Female 10 pin cable head (for extending enc. cables) | 3 |  |  |  |  | 41000574 |  |  | €0.37 | IDC hona kabel 10-pol guld 2.54mm |  | €1.10
 | 10 pin flat cable, per meter (for extending enc. cables) | 5 |  |  |  |  | 31670207 |  |  | €0.63 | Flatkabel grå 10 ledare 1.27mm /m |  | €3.14
 |  |  |  |  |  |  |  |  |  |  |  |  | €0.00
 | PC Connection |  |  |  |  |  |  |  |  |  |  |  | €0.00
 | Sensoray S826 | 1 |  |  |  |  |  |  | www.enciris.com | €793.73 | http://www.sensoray.com/products/826.htm | Order directly or through distributor | €793.73
 | DAQ Cable 26-pin | 1 |  |  | 2217642 |  |  |  |  | €4.14 | AMPHENOL FC26600-0 LEAD, 2.54MM, F/F, 600MM, 26WAY |  | €4.14
 | DAQ Cable 50-pin | 1 |  |  | 2217690 |  |  |  |  | €7.02 | AMPHENOL FC50600-0 LEAD, 2.54MM, F/F, 600MM, 50WAY |  | €7.02
 |  |  |  |  |  |  |  |  |  |  |  |  | €0.00
 |  |  |  |  |  |  |  |  |  |  |  |  | €0.00
 | ELECTRONICS CIRCUIT BOARDS |  |  |  |  |  |  |  |  |  |  |  | €0.00
 |  |  |  |  |  |  |  |  |  |  |  |  | €0.00
 | WoodenHaptics Motherboard |  |  |  |  |  |  |  |  |  |  |  | €0.00
 | PCB manufacturing (price based on order of 2 units) | 1 |  |  |  |  |  |  | pcb-pool.com | €69.00 |  |  | €69.00
 | motor & high pwr connectors | 4 |  |  | 1761541 |  |  |  |  | €0.31 | IMO PRECISION CONTROLS 20.155MH/2 HEADER, 3.5MM, HORIZ, 2WAY |  | €1.23
ALT | vertical connectors (4) | 0 |  |  | 1761550 |  |  |  |  | €0.31 | IMO PRECISION CONTROLS 20.155MV/2 HEADER, 3.5MM, 2WAY |  | €0.00
 | cable block high pwr | 4 |  |  | 1761532 |  |  |  |  | €0.84 | IMO PRECISION CONTROLS 20.1550M/2 TERMINAL BLOCK, 3.5MM, 2WAY |  | €3.34
 | 10 pin encoder connector | 3 |  |  | 2215290 |  |  |  |  | €0.90 | MULTICOMP MC9A22-1034 HEADER, THT, RIGHT ANGLE, 2.54MM, 10WAY |  | €2.69
ALT | 10 pin STRAIGHT encoder header (3x) | 0 |  |  | 2215304 |  |  |  |  | €0.49 | 61201021621 HEADER, THT, VERTICAL, 2.54MM, 10WAY |  | €0.00
 | micro usb connector, smd (non-reversed) | 1 |  |  | 1645325 |  |  |  |  | €1.48 | HIROSE(HRS) ZX62-B-5PA(11) MICRO USB, B TYPE, RECEPTACLE |  | €1.48
 | 20 pin socket (to ext. board) | 2 |  |  | 1593469 |  |  |  |  | €1.76 | MULTICOMP 2212S-20SG-85 SOCKET, PCB, 1 ROW, 20WAY |  | €3.51
 | 4 pin socket (to ext. board) | 1 |  |  | 1593460 |  |  |  |  | €0.39 | MULTICOMP 2212S-04SG-85 SOCKET, PCB, 1 ROW, 4WAY |  | €0.39
 | 18 pin (2x9) escon socket | 3 |  |  | 1668305 |  |  |  |  | €3.66 | SAMTEC SSQ-109-01-G-D RECEPTACLE, 2.54MM, DUAL, 18WAY |  | €10.97
 | 12 pin escon socket (1 pin discarded) | 3 |  |  | 1593465 |  |  |  |  | €0.16 | MULTICOMP 2212S-12SG-85 SOCKET, PCB, 1 ROW, 12WAY |  | €0.48
 | Encoder driver | 3 |  |  | 1103045 |  |  |  |  | €1.02 | TEXAS INSTRUMENTS AM26LS32ACD IC, DIFF LINE RECEIVER QUAD, 26LS32 |  | €3.06
 |  |  |  |  |  |  |  |  |  |  |  |  | €0.00
 | WoodenHaptics DAQ Extension Board |  |  |  |  |  |  |  |  |  |  |  | €0.00
 | PCB manufacturing (price based on order of 6 units) | 1 |  |  |  |  |  |  | pcb-pool.com | €15.70 |  |  | €15.70
 | 50 pin daq connector | 1 |  |  | 2215272 |  |  |  |  | €1.93 | AMPHENOL T816150A1S102CEU HEADER, L/LATCH, STR, 2.54MM, 50WAY | Should be replaced with low profile | €1.93
 | 26 pin daq connector | 1 |  |  | 2217535 |  |  |  |  | €1.71 | AMPHENOL T816126A1S102CEU HEADER, L/LATCH, STR, 2.54MM, 26WAY | Should be replaced with low profile | €1.71
 | 44 pins (50) ext. board | 1 |  |  | 3418388 |  |  |  |  | €2.76 | TE CONNECTIVITY / AMP 5-826629-0 HEADER, 1ROW, 50WAY |  | €2.76
 |  |  |  |  |  |  |  |  |  |  |  |  | €0.00
 | Box Enclosure Mounting |  |  |  |  |  |  |  |  |  |  |  | €0.00
 | Distance screws | 4 |  |  | 1466725 |  |  |  |  | €0.30 | ETTINGER SPACER, M3X, 5-VZK ETTINGER-05.13.051-SPACER, M3X, 5-VZK |  | €1.21
 | M3x6 screws (preferably M3x4 screws that comes with computers) | 4 |  |  | 1419986 |  |  |  |  | €0.02 | DURATOOL-M36 PRSTMCZ100--SCREW, STEEL, BZP, 6MM, M3, PK100 |  | €0.09
 | M3 washers | 4 |  |  | 1377536 |  |  |  |  | €0.01 | DURATOOL M3 BRASS FULL WASHER WASHER, FULL, BRASS, M3 |  | €0.04
 |  |  |  |  |  |  |  |  |  |  |  |  | €0.00
 | Recommended Equipment for Electronics Workbench |  |  |  |  |  |  |  |  |  |  |  | €0.00
 | Proper soldering station | 0 |  |  | 1447700 |  |  |  |  | €375.13 | WELLER WD 1000T (EU) SOLDERING STATION, 80W, 50DEG-450DEG, EU |  | €0.00
 | Proper oscilloscope (not really needed, for testing only) | 0 |  |  | 2191868 |  |  |  |  | €823.17 | TEKTRONIX DPO2002B OSCILLOSCOPE, 2CH, 70MHZ, 1GSPS |  | €0.00
 | Solder cleaner | 0 |  |  | 1792731 |  |  |  |  | €4.86 | WELLER CLEANER, WOOL, BRASS, WDC, PK2 WELLER-T0051384099-CLEANER, WOOL, BRASS, WDC, PK2 |  | €0.00
 | Solder activator | 0 |  |  | 873895 |  |  |  |  | €8.76 | WELLER TIP ACTIVATOR, LOW TEMP, 25G WELLER-TIP ACTIVATOR-TIP ACTIVATOR, LOW TEMP, 25G |  | €0.00
 | Solder 1.2 mm tip | 0 |  |  | 1282099 |  |  |  |  | €4.86 | WELLER TIP, SOLDERING IRON, ROUND, BENT, 1.2MM WELLER-LTF-TIP, SOLDERING IRON, ROUND, BENT, 1.2MM |  | €0.00
 | Solder 0.5 mm tip | 0 |  |  | 1282096 |  |  |  |  | €4.97 | WELLER TIP, SOLDERING IRON, ROUND, 0.5MM WELLER-LT1SA-TIP, SOLDERING IRON, ROUND, 0.5MM |  | €0.00
 | Organizer cabinet (Sortimentskåp) | 0 |  |  | 1367091 |  |  |  |  | €21.67 | RAACO CABINET, ORGANISER, 44COMPARTMENT |  | €0.00
 | De-soldering | 0 |  |  |  |  |  |  |  |  |  |  | €0.00
 | Tweezers | 0 |  |  | 1617218 |  |  |  |  | €81.80 | DURATOOL-D00840-TWEEZERS SET, ESD SAFE, 6PC |  | €0.00
 | Hack-cables | 0 |  |  |  |  |  |  |  |  |  |  | €0.00
 | Thin lead | 0 |  |  |  |  |  |  |  |  |  |  | €0.00
 | Thicker lead | 0 |  |  |  |  |  |  |  |  |  |  | €0.00
 | Scalpel | 0 |  |  |  |  |  |  |  |  |  |  | €0.00
 | Precision cutter | 0 |  |  |  |  |  |  |  |  |  |  | €0.00
 | Electrostatic mat kit with wristband and earth connector | 0 |  |  | 1736631 |  |  |  |  | €110.69 | MULTICOMP 069-0007 ESD WORKSTATION KIT, BLACK 0.7X1M |  | €0.00
 | Heat gun | 0 |  |  | 2473569 |  |  |  |  | €126.24 | STEINEL HL 2020 E EURO
 | Heat gun accessory for (reflector) for crimp tubes | 0 |  |  | 3116797 |  |  |  |  | €15.34 | STEINEL-070519-NOZZLE, REFLECTOR, SMALL
 |  | 0 |  |  |  |  |  |  |  |  |  |  | €0.00
 |  |  |  |  |  |  |  |  |  |  |  |  | €0.00
 | COMPUTER (OPTIONAL) |  |  |  |  |  |  |  |  |  |  |  | €0.00
 | ITX Motherboard AM1 (MSI AM1I) | 0 |  |  |  |  |  |  | Komplett.se 811857 | €25.29 | MSI AM1I, Socket-AM1 mini-ITX, DDR3, 1x-PCIe-x16, GbLAN, USB3.0, VGA, DVI, HDMI |  | €0.00
 | CPU (AMD Athlon 5350 APU) | 0 |  |  |  |  |  |  | Komplett.se 809078 | €46.48 | AMD Athlon 5350 Socket-AM1, Quad Core, 2.05GHz, 2MB, 25W, 28nm, Radeon R3-series, Boxed w/fan |  | €0.00
 | PSU Small form factor | 0 |  |  |  |  |  |  | Komplett.se 802785 | €39.37 | Silverstone ST30SF 300W PSU SFX, 80 Plus Bronze, Standard, 1x 6pin PCIe, 3x SATA, 2x Molex, 1x FD |  | €0.00
 | Wireless keyboard/trackpad combo | 0 |  |  |  |  |  |  | Komplett.se 645476 | €24.55 | Logitech Wireless Touch Keyboard K400 |  | €0.00
 | Case SilverStone Milo ML05B Black | 0 |  |  |  |  |  |  | inet.se | €63.39 | SilverStone Milo ML05B Svart |  | €0.00
 | PCIe flexible riser | 0 |  |  |  |  |  |  | inet.se | €10.48 | ASRock BTCPro Kit (PCIe riser) |  | €0.00

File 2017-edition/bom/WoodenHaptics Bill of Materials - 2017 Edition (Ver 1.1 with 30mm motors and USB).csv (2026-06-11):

 |  |  |  |  |  | Eur | USD | Sek
 | WoodenHaptics.org Bill of Materials and Recommended Equipment |  | Mechanics (without wood cut costs) |  |  | 209 | 221 | 1 979
 |  |  | Motors, encoders and current drivers |  |  | 1 475 | 1 564 | 13 983
 | We will try to reduce the number of distributors to reduce complexity |  | Other electronics |  |  | 199 | 211 | 1 886
 | Maxon, Farnell and Misumi is easy to access globally |  | Estimated total* part cost for kit: |  |  | 1 883 | 1 996 | 17 848
 | Other distributors might be tricky in some parts of the world
 | Let us know your experience in the forum of woodenhaptics.org |  | Estimated required tools cost: |  |  | 196 | 208 | 1 862
 | *) No labour cost included, i.e. for laser-cutting or soldering. |  | 1 EUR in SEK |  |  | kr9.48
 | Largest costs are in the motors, drivers and PCIe card that could |  | 1 EUR in USD |  |  | $1.06
 | be re-used in several projects if you so wish. Required tools |  | 1 EUR in CHF |  |  | CHF1.07
 | (except laser-cutter and soldering tools) are included.
 |  |  | Suggested distributor (Europe) part number |  |  |  |  |  | Estimated Unit Cost €
Alter- native | Our Name | quantity | Maxon | Farnell | Misumi | Elektrokit | Tecni-cable | Other Distributor |  | Sum Cost | Full name | Notes
 |  |  |  |  |  |  |  |  |  | €0.00
 | MECHANICS |  |  |  |  |  |  |  |  | €0.00
 |  |  |  |  |  |  |  |  |  | €0.00
 | Raw Material |  |  |  |  |  |  |  |  | €0.00
 | 6 mm birch plywood A2 sheet (594 x 420 mm) (alternatives possible) | 5 |  |  |  |  |  | Local / cutlasercut.com | €5.27 | €26.37
 |  |  |  |  |  |  |  |  |  | €0.00
 | Construction Hardware: Base |  |  |  |  |  |  |  |  | €0.00
 | M3x10 (for motor) | 6 |  |  | CB3-10 |  |  |  | €0.09 | €0.54
 | M3x35 | 6 |  |  | CB3-35 |  |  |  | €0.12 | €0.72
 | M3x50 | 4 |  |  | CB3-50 |  |  |  | €0.24 | €0.96
 | M5x90 | 6 |  |  | CB5-90 |  |  |  | €0.30 | €1.80
 | M3x22 | 10 |  |  | CB3-22 |  |  |  | €0.10 | €1.00
 | 6x10x1 washer | 6 |  |  | WSSB10-6-1 |  |  |  | €1.05 | €6.30
 | 10x55x4x5 capstan (10x55 shaft (RDOF10-55) ok if 10mm coupler) | 1 |  |  | SFRMHP10-55-F5-P4 |  |  |  | €7.36 | €7.36
 | 10x22x6 bearing | 2 |  |  | SB6900ZZ |  |  |  | €5.60 | €11.20
 | Flexible Coupler that fits 5mm motor shaft and 4 mm capstan | 1 |  |  | CPL12-4-5 |  |  |  | €19.00 | €19.00
ALT | For other motor sharfts use CPL12-3-4 etc (from your shaft to 4mm) | 0
 | 3x20 dowel pin | 4 |  |  | MS3-20 |  |  |  | €0.08 | €0.32
 | 3x40 dowel pin | 7 |  |  | MS3-40 |  |  |  | €0.20 | €1.40
 | 3x60 dowel pin (Substitute with MS3-40) | 5 |  |  | MS3-40 |  |  |  | €0.20 | €1.00
 |  |  |  |  |  |  |  |  |  | €0.00
 | Construction Hardware: Body A |  |  |  |  |  |  |  |  | €0.00
 | M3x10 (for motor) | 12 |  |  | CB3-10 |  |  |  | €0.09 | €1.08
 | 8x22x7 bearing | 2 |  |  | B608ZZ |  |  |  | €1.80 | €3.60
 | 10x22x6 bearing | 4 |  |  | SB6900ZZ |  |  |  | €5.60 | €22.40
 | M3x22 | 7 |  |  | CB3-22 |  |  |  | €0.10 | €0.70
 | M3x18 | 16 |  |  | CB3-18 |  |  |  | €0.09 | €1.44
 | M3x45 | 6 |  |  | CB3-45 |  |  |  | €0.17 | €1.02
 | M6/1.0 nut | 1 |  |  | LBNR6 |  |  |  | €0.32 | €0.32
 | M4x45 full thread (thread M4/0.75) | 1 |  |  | ACB4-45 |  |  |  | €0.35 | €0.35
 | M4/0.75 nut | 1 |  |  | LBNR4 |  |  |  | €0.28 | €0.28
 | 8x60 Shoulder bolt | 1 |  |  | MSB8-60 |  |  |  | €0.80 | €0.80
 | 8x110 Shoulder bolt (thread M6/1.0) | 1 |  |  | MSB8-110 |  |  |  | €1.00 | €1.00
 | 8x05 Belleville (spring) washer | 1 |  |  | SSRBW8 |  |  |  | €1.05 | €1.05
 | 8x14x05 shim | 6 |  |  | CIMR8-14-0.5 |  |  |  | €0.50 | €3.00
 | Flexible Coupler that fits 5mm motor shaft and 4 mm capstan | 2 |  |  | CPL12-4-5 |  |  |  | €19.00 | €38.00
 | 10x55x4x5 capstan (10x55 shaft (RDOF10-55) ok if 10mm coupler) | 2 |  |  | SFRMHP10-55-F5-P4 |  |  |  | €7.36 | €14.72
 |  |  |  |  |  |  |  |  |  | €0.00
 | Construction Hardware: Body B |  |  |  |  |  |  |  |  | €0.00
 | 8x14x05 shim | 1 |  |  | CIMR8-14-0.5 |  |  |  | €0.42 | €0.42
 | 8x05 Belleville (spring) washer | 1 |  |  | SSRBW8 |  |  |  | €1.05 | €1.05
 | 3x25 pin | 9 |  |  | MS3-25 |  |  |  | €0.20 | €1.80
 | M3x22 | 11 |  |  | CB3-22 |  |  |  | €0.10 | €1.10
 | 8x22x7 bearing | 4 |  |  | B608ZZ |  |  |  | €1.80
 | M4x45 full thread (thread M4/0.75) | 1 |  |  | ACB4-45 |  |  |  | €0.35 | €0.35
 | M4/0.75 nut | 1 |  |  | LBNR4 |  |  |  | €0.28 | €0.28
 |  |  |  |  |  |  |  |  |  | €0.00
 | Construction Hardware: Body C |  |  |  |  |  |  |  |  | €0.00
 | M3x30 | 4 |  |  | CB3-30 |  |  |  | €0.12 | €0.48
 | M3x18 | 2 |  |  | CB3-18 |  |  |  | €0.09 | €0.18
 | 3x20 dowel pin | 2 |  |  | MS3-20 |  |  |  | €0.08 | €0.16
 | 3x35 dowel pin (3x30 preferred) | 4 |  |  | MS3-35 |  |  |  | €0.20 | €0.80
 | 8x60 shoulder bolt | 1 |  |  | MSB8-60 |  |  |  | €0.80 | €0.80
 | 8x14x05 shim | 9 |  |  | CIMR8-14-0.5 |  |  |  | €0.42 | €3.78
 | 8x05 belleville (spring) washer | 1 |  |  | SSRBW8 |  |  |  | €1.05 | €1.05
 | M6 nut (1mm thread) | 1 |  |  | LBNR6 |  |  |  | €0.32 | €0.32
 | M4 35 mm screw with "nut" cap | 1 |  |  | HXN-STC-M4-35
 | Red ball door knob | 1 |  |  |  |  |  | Clas Ohlson:
 |  |  |  |  |  |  |  |  |  | €0.00
 | Construction Hardware: Body C' |  |  |  |  |  |  |  |  | €0.00
 | M4x45 full thread (thread M4/0.75) | 1 |  |  | ACB4-45 |  |  |  | €0.35 | €0.35
 | M4/0.75 nut | 1 |  |  | LBNR4 |  |  |  | €0.28 | €0.28
 | M3x22 | 7 |  |  | CB3-22 |  |  |  | €0.10 | €0.70
 | 8x22x7 bearing | 2 |  |  | B608ZZ |  |  |  | €1.80 | €3.60
 | 3x35 dowel pin | 4 |  |  | MS3-35 |  |  |  | €0.20 | €0.80
 | M3x35 | 3 |  |  | CB3-35 |  |  |  | €0.12 | €0.36
 | 8x14x05 shim | 6 |  |  | CIMR8-14-0.5 |  |  |  | €0.42 | €2.52
 |  |  |  |  |  |  |  |  |  | €0.00
 | Construction Hardware: Cabling |  |  |  |  |  |  |  |  | €0.00
 | Wire rope 7x7 core, 0.54 mm (more threads preferable) | 10 |  |  |  |  | 603.000.540 |  | €0.89 | €8.89 | 0.54mm 7x7 A4-AISI 316 Stainless Steel Cable MBL 16kgs - 603.000.540
 | Double ferrule (for crimping onto wire rope) | 20 |  |  |  |  | 115.000.700 |  | €0.24 | €4.77 | Code 0.7 Double Copper Ferrule
 | Turnbuckle (spannschloss) | 1 |  |  |  |  |  | Hobbykellershop.eu: 018-3051 | €6.17 | €6.17 | Spannschloss M2.5 - High Precision
 |  |  |  |  |  |  |  |  |  | €0.00
 | Required Tools for Mechanics Workbench |  |  |  |  |  |  |  |  | €0.00
 | Arbor Press | 1 |  |  |  |  |  | Schuchardt Maskin smaskin.se | €91.77 | €91.77 | Verkstadspress (smallest) | Chose a larger next time
 | Wire rope cutter | 1 |  |  |  |  | 100.004.062 |  | €9.92 | €9.92 | Budget Wire Rope Cutter up to 3mm Diameter - 100.004.062 | Chose a better and more expensive
 | Wire rope ferrule crimper (you really need this) | 1 |  |  |  |  | 115.007.023 |  | €51.27 | €51.27 | TECNI®Cable Crimp Tool for Double Copper Ferrules - 115.007.023
 | Torch | 1 |  |  |  |  |  | Teknikmagasinet.se 340927 | €24.26 | €24.26
 | Torch gas | 1 |  |  |  |  |  | Teknikmagasinet.se 340927 | €3.16 | €3.16
 | Hex keys | 1 |  |  |  |  |  | Local | €8.00 | €8.00
 | Mini-hex key 1.3mm (M2.5) for flexible couplers | 1 |  |  |  |  |  | Digi-key
 | Adjustable wrench | 1 |  |  |  |  |  | Local | €8.00 | €8.00
 |  |  |  |  |  |  |  |  |  | €0.00
 | Other |  |  |  |  |  |  |  |  | €0.00
 | Rubber feet (from a computer case; SilverStone Milo ML05B Black) | 4 |  |  |  |  |  |  | €1.00 | €4.00
 |  |  |  |  |  |  |  |  |  | €0.00
 | ELECTRONICS |  |  |  |  |  |  |  |  | €0.00
 |  |  |  |  |  |  |  |  |  | €0.00
 | Electronics Box |  |  |  |  |  |  |  |  | €0.00
 | WoodenHaptics Motherboard (see below) | 1 |  |  |  |  |  |  |  | €0.00
 | WoodenHaptics DAQ Extension board (see below) /or/ | 0 |  |  |  |  |  |  |  | €0.00
 | mbed.org M3 extension board (for USB experimental) | 1 |  | 1761179 |  |  |  |  | €51.45 | €51.45 | NXP OM11043 LPC1768, MBED PROTOTYPING BOARD, KIT | The chip alone is only 90kr
 |  |  |  |  |  |  |  |  |  | €0.00
 | Power Supply |  |  |  |  |  |  |  |  | €0.00
 | 19.5V power supply 5A | 1 |  |  |  |  |  | Liontech AB | €37.97 | €37.97 | Innergy PowerGear 90
 |  |  |  |  |  |  |  |  |  | €0.00
 | Electric Cables |  |  |  |  |  |  |  |  | €0.00
 | 12mm sleeves (5m) | 1 |  | 1297228 |  |  |  |  | €3.02 | €3.02 | PRO POWER, SLEEVING, BRAID, 12MM, BLACK, 5M, PRO POWER-PETBK12BG5-SLEEVING, BRAID, 12MM, BLACK, 5M
 | Male 10 pin cable head (for extending enc.cables) | 3 |  |  |  | 41011859 |  |  | €1.66 | €4.97 | IDC hane kabel 10-pol 2.54mm
 | Female 10 pin cable head (for extending enc. cables) | 3 |  |  |  | 41000574 |  |  | €0.37 | €1.10 | IDC hona kabel 10-pol guld 2.54mm
 | 10 pin flat cable, per meter (for extending enc. cables) | 5 |  |  |  | 31670207 |  |  | €0.63 | €3.13 | Flatkabel grå 10 ledare 1.27mm /m
 |  |  |  |  |  |  |  |  |  | €0.00
 | PC Connection |  |  |  |  |  |  |  |  | €0.00
 | Sensoray S826 | 0 |  |  |  |  |  | www.enciris.com | €707.02 | €0.00 | http://www.sensoray.com/products/826.htm | Order directly or through distributor
 | DAQ Cable 26-pin | 0 |  | 2217642 |  |  |  |  | €4.12 | €0.00 | AMPHENOL FC26600-0 LEAD, 2.54MM, F/F, 600MM, 26WAY
 | DAQ Cable 50-pin | 0 |  | 2217646 |  |  |  |  | €7.00 | €0.00 | AMPHENOL FC50600-0 LEAD, 2.54MM, F/F, 600MM, 50WAY
 |  |  |  |  |  |  |  |  |  | €0.00
 | Motors, Encoders & Current driver |  |  |  |  |  |  |  |  | €0.00
 | Maxon 30mm (310009) & 500 CPR Encoder combination | 3 | 310009 |  |  |  |  |  | €348.60 | €1,045.79
 | Maxon 50/5 driver module (could eventually be custom made) | 3 | 438725 |  |  |  |  |  | €143.08 | €429.25 | ESCON Module 50/5, 4-Q Servocontroller for DC/EC motors, 5/15 A, 10 - 50 VDC
 | ELECTRONICS CIRCUIT BOARDS |  |  |  |  |  |  |  |  | €0.00
 |  |  |  |  |  |  |  |  |  | €0.00
 | WoodenHaptics Motherboard |  |  |  |  |  |  |  |  | €0.00
 | PCB manufacturing (price based on order of 2 units) | 1 |  |  |  |  |  | pcb-pool.com | €69.00 | €69.00
 | motor & high pwr connectors | 4 |  | 1761541 |  |  |  |  | €0.31 | €1.22 | IMO PRECISION CONTROLS 20.155MH/2 HEADER, 3.5MM, HORIZ, 2WAY
 | cable block high pwr | 4 |  | 1761532 |  |  |  |  | €0.83 | €3.33 | IMO PRECISION CONTROLS 20.1550M/2 TERMINAL BLOCK, 3.5MM, 2WAY
 | 10 pin encoder connector | 3 |  | 2215290 |  |  |  |  | €0.65 | €1.96 | AMPHENOL T821110A1R100CEU Kabel-till-kort kontaktdon, Right Angle, T821 Serien, 10 Kontakt(-er), Hylsstickpropp, 2.54 mm
 | micro usb connector, smd (non-reversed) (make one with holes next) | 1 |  | 2293753 |  |  |  |  | €1.47 | €1.47
 | 20 pin socket (to ext. board) | 2 |  | 1593469 |  |  |  |  | €2.05 | €4.09 | MULTICOMP 2212S-20SG-85 SOCKET, PCB, 1 ROW, 20WAY
 | 4 pin socket (to ext. board) | 1 |  | 1593460 |  |  |  |  | €0.39 | €0.39 | MULTICOMP 2212S-04SG-85 SOCKET, PCB, 1 ROW, 4WAY
 | 18 pin (2x9) escon socket | 3 |  | 1668305 |  |  |  |  | €3.64 | €10.93 | SAMTEC SSQ-109-01-G-D RECEPTACLE, 2.54MM, DUAL, 18WAY
 | 12 pin escon socket (1 pin discarded) | 3 |  | 1593465 |  |  |  |  | €0.16 | €0.47 | MULTICOMP 2212S-12SG-85 SOCKET, PCB, 1 ROW, 12WAY
 | Encoder driver | 3 |  | 1103045 |  |  |  |  | €1.02 | €3.05 | TEXAS INSTRUMENTS AM26LS32ACD IC, DIFF LINE RECEIVER QUAD, 26LS32
 |  |  |  |  |  |  |  |  |  | €0.00
 | WoodenHaptics DAQ Extension Board |  |  |  |  |  |  |  |  | €0.00
 | PCB manufacturing (price based on order of 6 units) | 0 |  |  |  |  |  | pcb-pool.com | €15.70 | €0.00
 | 50 pin daq connector | 0 |  | 2217539 |  |  |  |  | €1.92 | €0.00 | AMPHENOL T816150A1S102CEU HEADER, L/LATCH, STR, 2.54MM, 50WAY | Should be replaced with low profile
 | 26 pin daq connector | 0 |  | 2217535 |  |  |  |  | €1.71 | €0.00 | AMPHENOL T816126A1S102CEU HEADER, L/LATCH, STR, 2.54MM, 26WAY | Should be replaced with low profile
 | 44 pins (50) ext. board | 0 |  | 3418388 |  |  |  |  | €2.75 | €0.00 | TE CONNECTIVITY / AMP 5-826629-0 HEADER, 1ROW, 50WAY
 |  |  |  |  |  |  |  |  |  | €0.00
 | Box Enclosure Mounting |  |  |  |  |  |  |  |  | €0.00
 | Distance screws | 4 |  | 1466725 |  |  |  |  | €0.30 | €1.20 | ETTINGER SPACER, M3X, 5-VZK ETTINGER-05.13.051-SPACER, M3X, 5-VZK
 | M3x6 screws (preferably M3x4 screws that comes with computers) | 4 |  | 1419986 |  |  |  |  | €0.02 | €0.09 | DURATOOL-M36 PRSTMCZ100--SCREW, STEEL, BZP, 6MM, M3, PK100
 | M3 washers | 4 |  | 1377536 |  |  |  |  | €0.01 | €0.04 | DURATOOL M3 BRASS FULL WASHER WASHER, FULL, BRASS, M3
 |  |  |  |  |  |  |  |  |  | €0.00
 | Recommended Equipment for Electronics Workbench |  |  |  |  |  |  |  |  | €0.00
 | 0.85mm hex key for encoders (these will be shipped with some enc.) | 0
 | Proper soldering station | 0 |  | 1447700 |  |  |  |  | €373.94 | €0.00 | WELLER WD 1000T (EU) SOLDERING STATION, 80W, 50DEG-450DEG, EU
 | Proper oscilloscope (not really needed, for testing only) | 0 |  | 2191868 |  |  |  |  | €820.57 | €0.00 | TEKTRONIX DPO2002B OSCILLOSCOPE, 2CH, 70MHZ, 1GSPS
 | Solder cleaner | 0 |  | 1792731 |  |  |  |  | €4.85 | €0.00 | WELLER CLEANER, WOOL, BRASS, WDC, PK2 WELLER-T0051384099-CLEANER, WOOL, BRASS, WDC, PK2
 | Solder activator | 0 |  | 873895 |  |  |  |  | €8.73 | €0.00 | WELLER TIP ACTIVATOR, LOW TEMP, 25G WELLER-TIP ACTIVATOR-TIP ACTIVATOR, LOW TEMP, 25G
 | Solder 1.2 mm tip | 0 |  | 1282099 |  |  |  |  | €4.85 | €0.00 | WELLER TIP, SOLDERING IRON, ROUND, BENT, 1.2MM WELLER-LTF-TIP, SOLDERING IRON, ROUND, BENT, 1.2MM
 | Solder 0.5 mm tip | 0 |  | 1282096 |  |  |  |  | €4.96 | €0.00 | WELLER TIP, SOLDERING IRON, ROUND, 0.5MM WELLER-LT1SA-TIP, SOLDERING IRON, ROUND, 0.5MM
 | Organizer cabinet (Sortimentskåp) | 0 |  | 1367091 |  |  |  |  | €21.60 | €0.00 | RAACO CABINET, ORGANISER, 44COMPARTMENT
 | De-soldering | 0 |  |  |  |  |  |  |  | €0.00
 | Tweezers http://www.lindstromtools.com/pdf.php | 0 |  |  |  |  |  |  |  | €0.00
 | Hack-cables | 0 |  |  |  |  |  |  |  | €0.00
 | Thin lead | 0 |  |  |  |  |  |  |  | €0.00
 | Thicker lead | 0 |  |  |  |  |  |  |  | €0.00
 | Scalpel | 0 |  |  |  |  |  |  |  | €0.00
 | Precision cutter | 0 |  |  |  |  |  |  |  | €0.00
 | Electrostatic wristband | 0 |  |  |  |  |  |  |  | €0.00
 | Mat | 0 |  |  |  |  |  |  |  | €0.00
 |  |  |  |  |  |  |  |  |  | €0.00
 | COMPUTER (OPTIONAL) |  |  |  |  |  |  |  |  | €0.00
 | ITX Motherboard AM1 (MSI AM1I) | 0 |  |  |  |  |  | Komplett.se 811857 | €25.21 | €0.00 | MSI AM1I, Socket-AM1 mini-ITX, DDR3, 1x-PCIe-x16, GbLAN, USB3.0, VGA, DVI, HDMI
 | CPU (AMD Athlon 5350 APU) | 0 |  |  |  |  |  | Komplett.se 809078 | €46.33 | €0.00 | AMD Athlon 5350 Socket-AM1, Quad Core, 2.05GHz, 2MB, 25W, 28nm, Radeon R3-series, Boxed w/fan
 | PSU Small form factor | 0 |  |  |  |  |  | Komplett.se 802785 | €39.24 | €0.00 | Silverstone ST30SF 300W PSU SFX, 80 Plus Bronze, Standard, 1x 6pin PCIe, 3x SATA, 2x Molex, 1x FD
 | Wireless keyboard/trackpad combo | 0 |  |  |  |  |  | Komplett.se 645476 | €24.47 | €0.00 | Logitech Wireless Touch Keyboard K400
 | Case SilverStone Milo ML05B Black | 0 |  |  |  |  |  | inet.se | €63.19 | €0.00 | SilverStone Milo ML05B Svart
 | PCIe flexible riser | 0 |  |  |  |  |  | inet.se | €10.44 | €0.00 | ASRock BTCPro Kit (PCIe riser)
 |  |  |  |  |  |  |  |  |  | €0.00
 |  |  |  |  |  |  |  |  |  | €0.00
 |  |  |  |  |  |  |  |  |  | €0.00
 |  |  |  |  |  |  |  |  |  | €0.00
 |  |  |  |  |  |  |  |  |  | €0.00
 |  |  |  |  |  |  |  |  |  | €0.00
 |  |  |  |  |  |  |  |  |  | €0.00
 |  |  |  |  |  |  |  |  |  | €0.00
 |  |  |  |  |  |  |  |  |  | €0.00
 |  |  |  |  |  |  |  |  |  | €0.00
 |  |  |  |  |  |  |  |  |  | €0.00
 |  |  |  |  |  |  |  |  |  | €0.00
 |  |  |  |  |  |  |  |  |  | €0.00
 |  |  |  |  |  |  |  |  |  | €0.00
 |  |  |  |  |  |  |  |  |  | €0.00
 |  |  |  |  |  |  |  |  |  | €0.00
 |  |  |  |  |  |  |  |  |  | €0.00
 |  |  |  |  |  |  |  |  |  | €0.00
 |  |  |  |  |  |  |  |  |  | €0.00
 |  |  |  |  |  |  |  |  |  | €0.00
 |  |  |  |  |  |  |  |  |  | €0.00
 |  |  |  |  |  |  |  |  |  | €0.00
 |  |  |  |  |  |  |  |  |  | €0.00
 |  |  |  |  |  |  |  |  |  | €0.00
 |  |  |  |  |  |  |  |  |  | €0.00
 |  |  |  |  |  |  |  |  |  | €0.00
 |  |  |  |  |  |  |  |  |  | €0.00
 |  |  |  |  |  |  |  |  |  | €0.00
 |  |  |  |  |  |  |  |  |  | €0.00
 |  |  |  |  |  |  |  |  |  | €0.00
 |  |  |  |  |  |  |  |  |  | €0.00
 |  |  |  |  |  |  |  |  |  | €0.00
 |  |  |  |  |  |  |  |  |  | €0.00
 |  |  |  |  |  |  |  |  |  | €0.00
 |  |  |  |  |  |  |  |  |  | €0.00
 |  |  |  |  |  |  |  |  |  | €0.00
 |  |  |  |  |  |  |  |  |  | €0.00
 |  |  |  |  |  |  |  |  |  | €0.00
 |  |  |  |  |  |  |  |  |  | €0.00
 |  |  |  |  |  |  |  |  |  | €0.00
 |  |  |  |  |  |  |  |  |  | €0.00
 |  |  |  |  |  |  |  |  |  | €0.00
 |  |  |  |  |  |  |  |  |  | €0.00

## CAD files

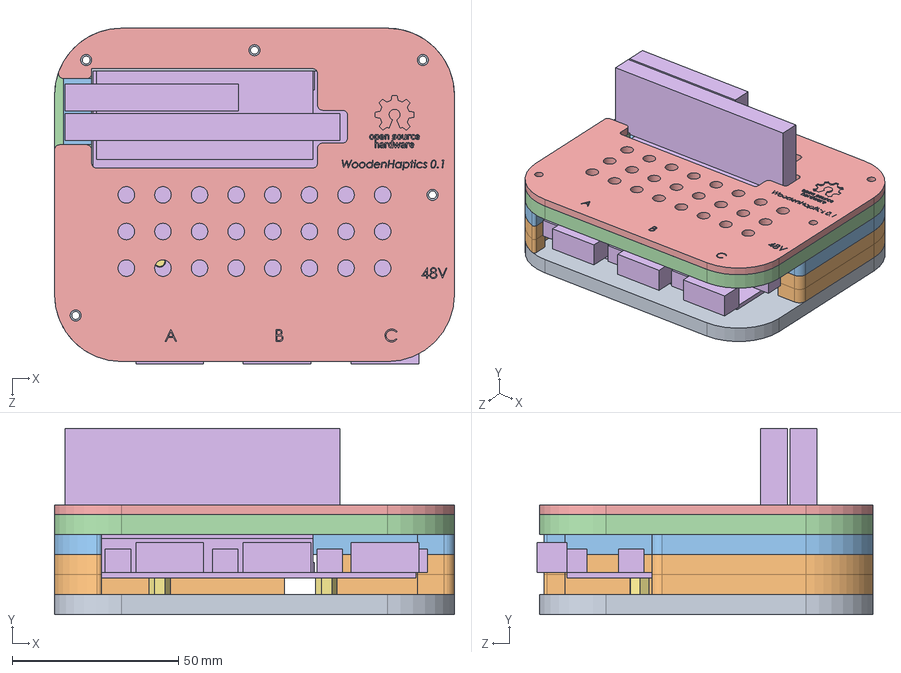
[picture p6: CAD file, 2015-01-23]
Electronics/Case/box.SLDASM
120.2 x 55.9 x 100.8 mm
box_5_acrylic
board_outer_dimensions
spacer_M3x6mm_plus_5mm_height x 4

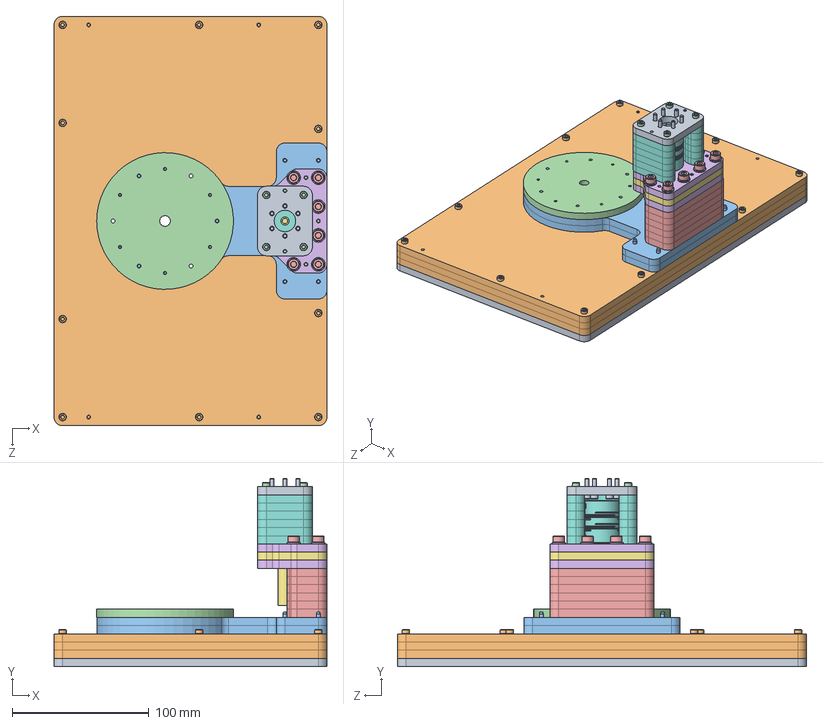
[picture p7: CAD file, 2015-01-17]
Mechanics/base/base_assembly.SLDASM
200.0 x 137.8 x 300.0 mm
base_plate_1
base_plate_2 x 3
base_plate_3 x 2
base_plate_4
base_tower_1 x 6
base_tower_2 x 2
base_tower_3
base_tower_4 x 6
base_tower_5_top
base_M3x22 x 10
base_M3x35 x 6
base_M3x50 x 4
base_M5x90 x 6
base_6x10x1_washer x 6
base_10x55x4x5_capstan
base_25x6x10_coupler
base_M3x12 x 6
base_3x20_dowel_pin x 4
base_3x40_dowel_pin x 7
base_3x60_dowel_pin x 5
base_10x22x6_bearing_Misumi_SB6900ZZ x 2

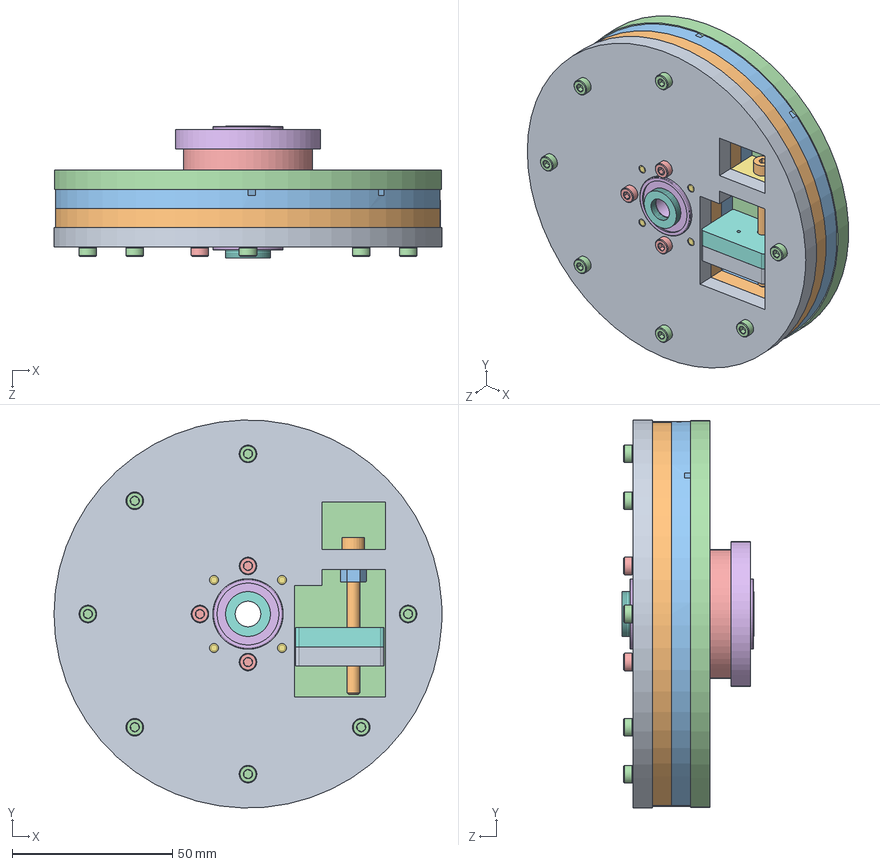
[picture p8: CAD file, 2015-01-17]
Mechanics/body_c_prim/body_c_prim_assembly.SLDASM
121.2 x 121.1 x 41.3 mm
body_c_prim_1
body_c_prim_2
body_c_prim_3
body_c_prim_4
body_c_prim_5
body_c_prim_6
body_c_prim_tension_screw_holder
body_c_prim_cable_tensioner_1
body_c_prim_cable_tensioner_2
body_c_prim_M4x45_full_thread_Misumi_ACB4_45
body_c_prim_M4_nut_Misumi-ANN4-0.5
body_c_prim_M3x22_McMaster_91290A124 x 7
body_c_prim_M3x35_McMaster_91290A135 x 3
body_c_prim_8x22x7_bearing_Misumi_B608ZZ x 2
body_c_prim_3x35_dowel_pin x 4
body_c_prim_8x14x05_shim_McMaster_98055A114 x 6

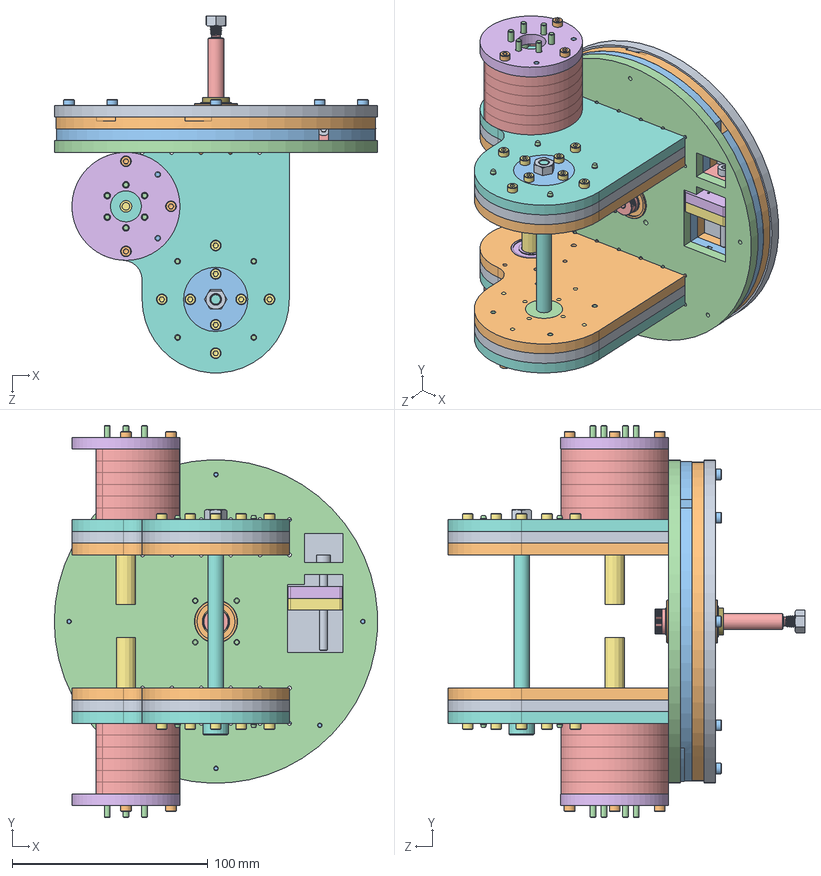
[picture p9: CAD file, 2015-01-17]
Mechanics/body_a/body_a_assembly.SLDASM
165.2 x 200.2 x 182.1 mm
body_a_turntable_1
body_a_turntable_2
body_a_turntable_3
body_a_turntable_4
body_a_tension_screw_holder
body_a_cable_tensioner_1
body_a_cable_tensioner_2
body_a_shaft_holder_outer x 2
body_a_shaft_holder_middle x 2
body_a_shaft_holder_inner x 2
body_a_shaft_piece_screw_holes x 2
body_a_shaft_piece_small x 4
body_a_motor_holder_cutout x 12
body_a_motor_holder x 2
body_a_M3x18_Misumi x 16
body_a_8x110_bolt
body_a_M4x45_full_thread_Misumi_ACB4_45
body_a_8x22x7_bearing_Misumi_B608ZZ x 2
body_a_M3x22 x 7
body_a_3x20_dowel_pin x 12
body_a_M4_075_thread_nut_Misumi_LBNR4
body_a_10x22x6_bearing_Misumi_SB6900ZZ x 4
body_a_10x55x4x5_capstan x 2
body_a_25x6x10_coupler x 2
body_a_M6_1_thread_nut_Misumi_LBNR6 x 2
body_a_M3x45_Misumi_CB3-45 x 6
body_a_3x40_dowel_pin x 4
body_a_M3x12 x 12
body_a_8x60_shoulder_bolt_McMaster_92981A215
body_a_8x05_spring_washer_McMaster_94065K340
body_a_8x14x05_shim_McMaster_98055A114 x 6

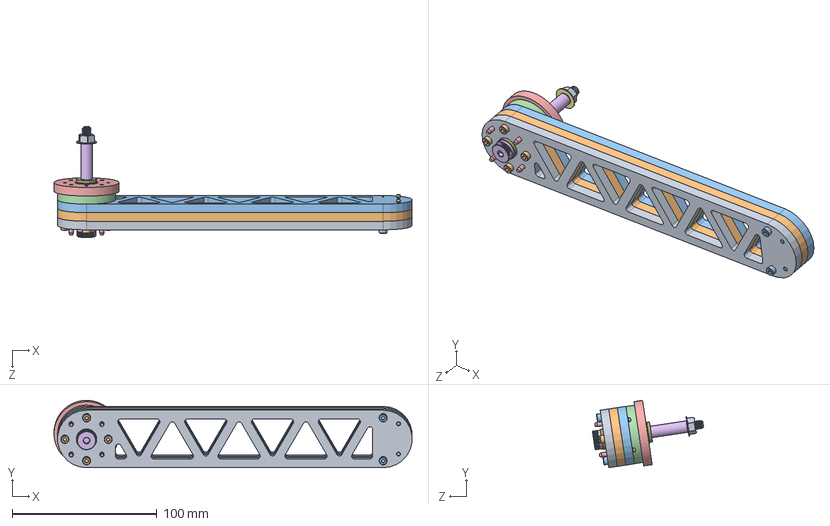
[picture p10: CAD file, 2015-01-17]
Mechanics/body_c/body_c_assembly.SLDASM
247.4 x 46.6 x 76.9 mm
body_c_1
body_c_2
body_c_3
body_c_4
body_c_5
body_c_8x60_shoulder_bolt_McMaster_92981A215
body_c_8x14x05_shim_McMaster_98055A114 x 9
body_c_8x05_spring_washer_McMaster_94065K340
body_c_M6_1_thread_nut_Misumi_LBNR6
body_c_M3x30_Misumi_CB3-30 x 4
body_c_M3x18_Misumi x 2
body_c_3x20_dowel_pin x 2
body_c_3x35_dowel_pin x 4

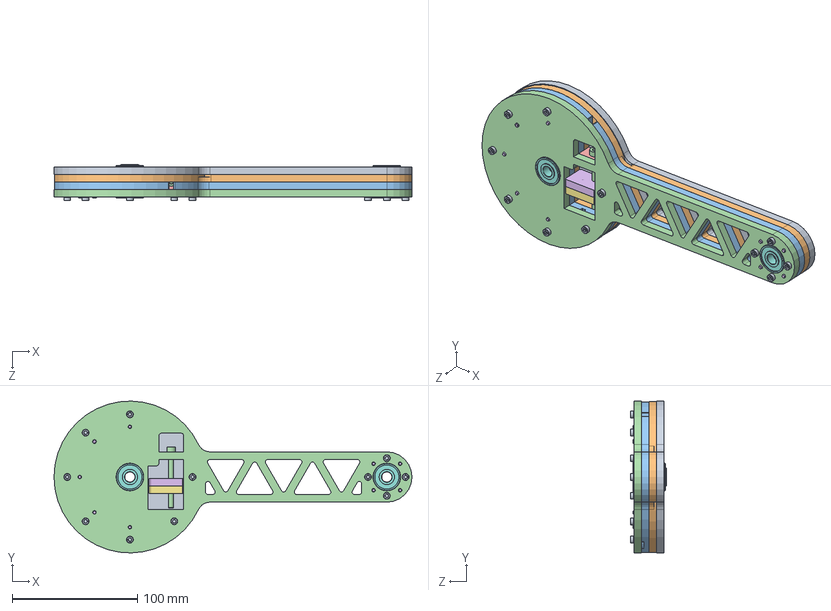
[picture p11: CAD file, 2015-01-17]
Mechanics/body_b/body_b_assembly.SLDASM
285.7 x 121.1 x 29.1 mm
body_b_1
body_b_2
body_b_3
body_b_4
body_b_tension_screw_holder
body_b_cable_tensioner_1
body_b_cable_tensioner_2
body_b_8x22x7_bearing_Misumi_B608ZZ x 4
body_b_M3x22_McMaster_91290A124 x 11
body_b_8x05_spring_washer_McMaster_94065K340
body_b_8x14x05_shim_McMaster_98055A114
body_b_M4x45_full_thread_Misumi_ACB4_45
body_b_M4_075_thread_nut_Misumi_LBNR4
body_b_3x25_dowel_pin x 9

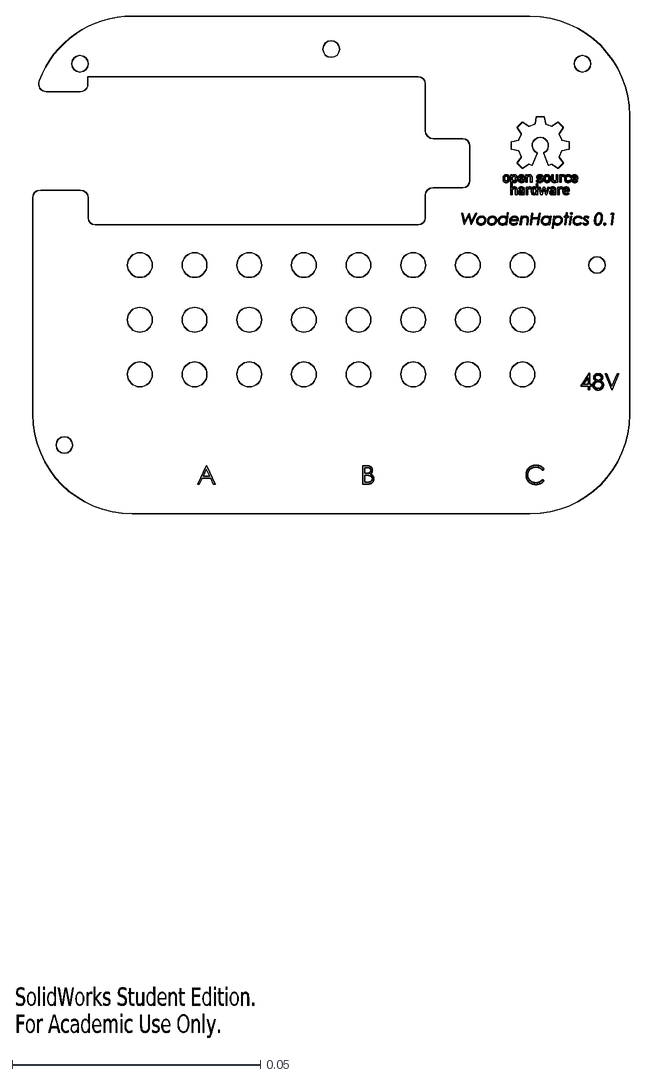
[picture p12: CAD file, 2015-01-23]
Electronics/Case/lasercut/electronics_box_3-6mm_A4_acrylic_or_plywood_2_of_2.DXF
SolidWorks Student Edition.
For Academic Use Only.

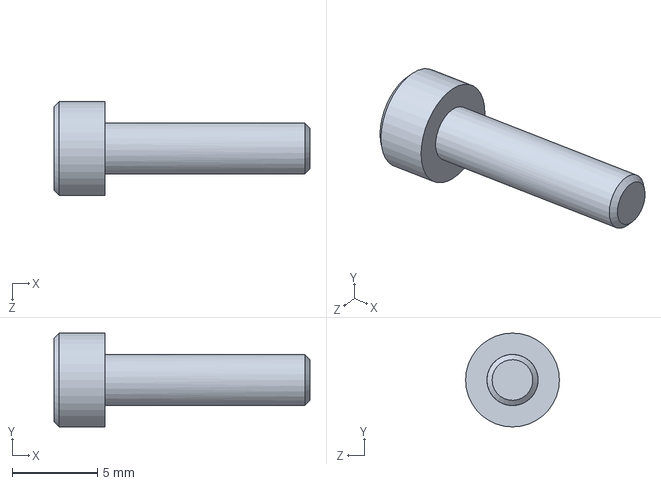
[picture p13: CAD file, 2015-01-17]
Mechanics/body_a/body_a_M3x12.SLDPRT
15.0 x 5.50 x 5.50 mm

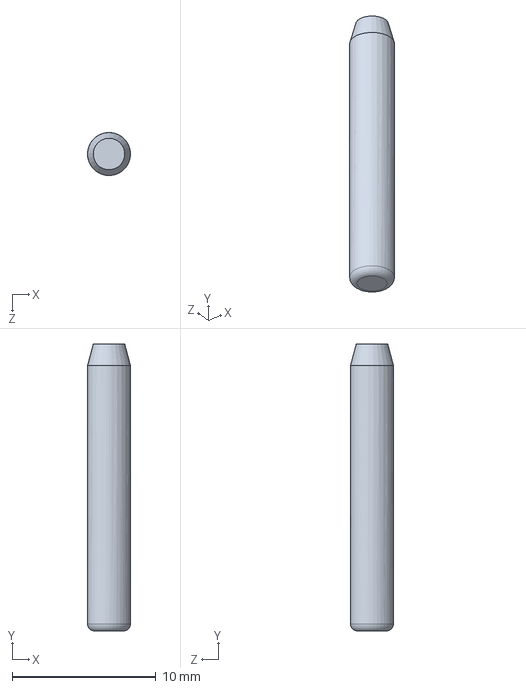
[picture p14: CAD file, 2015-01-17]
Mechanics/body_c/body_c_3x20_dowel_pin.SLDPRT
3.00 x 20.0 x 3.00 mm

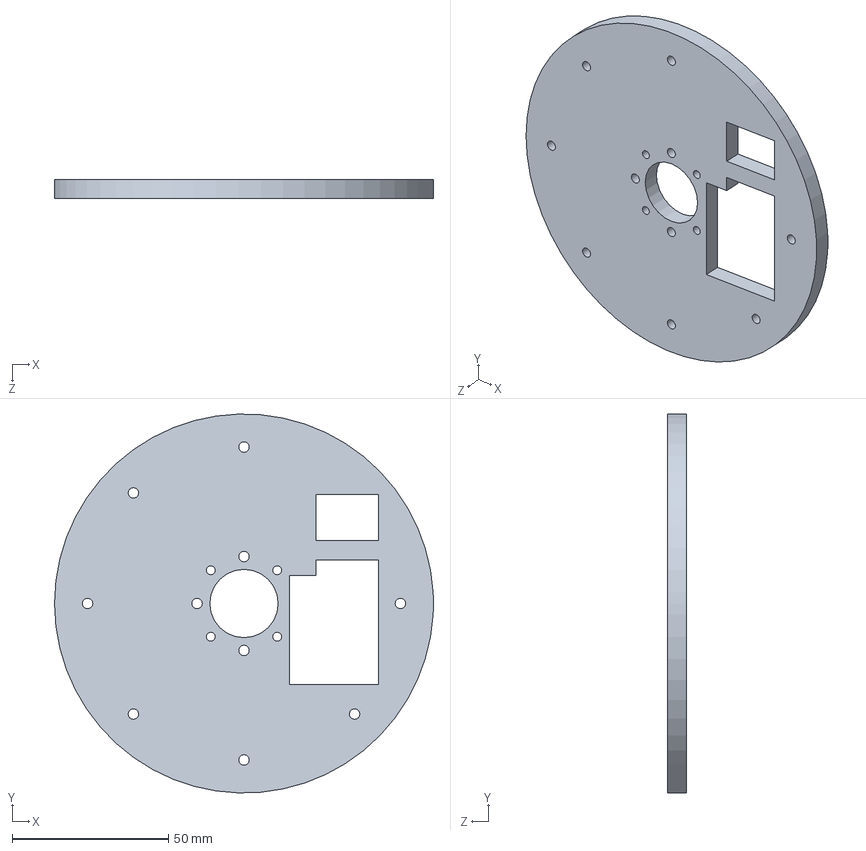
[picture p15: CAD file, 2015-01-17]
Mechanics/body_c_prim/body_c_prim_1.SLDPRT
121.2 x 121.1 x 6.00 mm

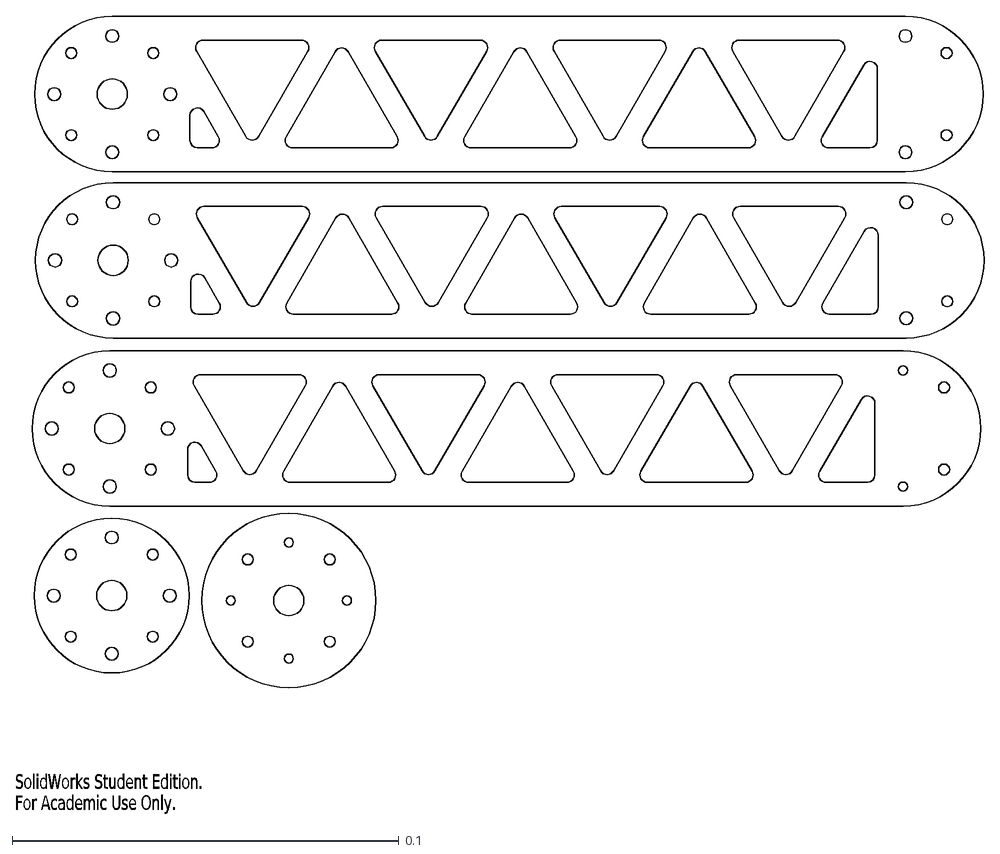
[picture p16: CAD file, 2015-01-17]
Mechanics/lasercut_drawings/dxf/body_c_A4_sheet_1_of_1.DXF
SolidWorks Student Edition.
For Academic Use Only.

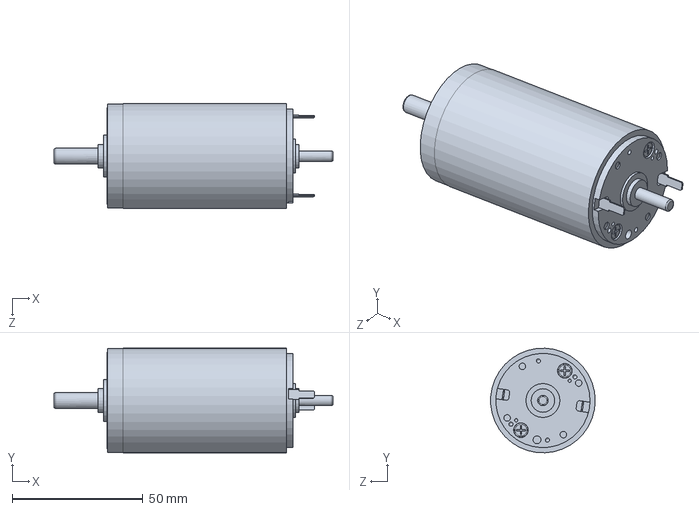
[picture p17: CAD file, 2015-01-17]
Mechanics/other/RE40-148866.SLDPRT
106.6 x 40.0 x 39.9 mm

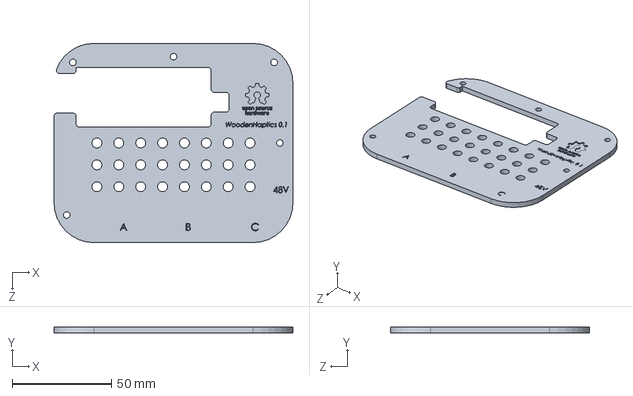
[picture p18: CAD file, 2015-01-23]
Electronics/Case/box_5_acrylic.SLDPRT
120.2 x 3.00 x 100.2 mm

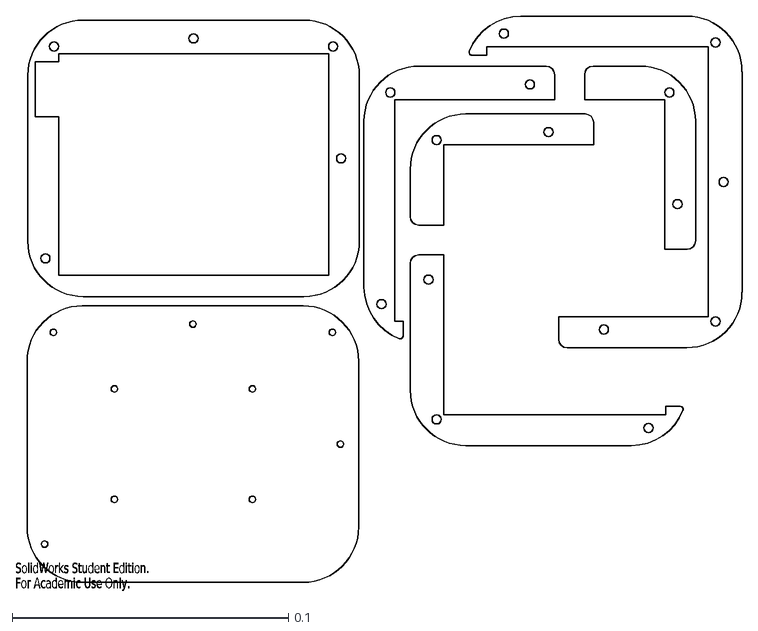
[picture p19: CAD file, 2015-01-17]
Electronics/Case/lasercut/electronics_box_6mm_A4_plywood_1_of_2.DXF
SolidWorks Student Edition.
For Academic Use Only.

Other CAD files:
Mechanics/base/base_tower_3.SLDPRT
Mechanics/body_c/body_c_3x35_dowel_pin.SLDPRT
Mechanics/body_c_prim/body_c_prim_3.SLDPRT
Mechanics/lasercut_drawings/dxf/body_c_prim_A3_sheet_1_of_1.DXF
Electronics/Case/board_outer_dimensions.SLDPRT
Electronics/Case/box_1.SLDPRT
Electronics/Case/box_2.SLDPRT
Electronics/Case/box_3.SLDPRT
Electronics/Case/box_4.SLDPRT
Electronics/Case/electronics_box_3-6mm_A4_acrylic_or_plywood_2_of_2.SLDDRW
Electronics/Case/electronics_box_6mm_A4_plywood_1_of_2.SLDDRW
Electronics/Case/spacer_M3x6mm_plus_5mm_height.SLDPRT
Mechanics/base/base_10x22x6_bearing_Misumi_SB6900ZZ.SLDPRT
Mechanics/base/base_10x55x4x5_capstan.SLDPRT
Mechanics/base/base_25x6x10_coupler.SLDPRT
Mechanics/base/base_3x40_dowel_pin.SLDPRT
Mechanics/base/base_3x60_dowel_pin.SLDPRT
Mechanics/base/base_6x10x1_washer.SLDPRT
Mechanics/base/base_A2_sheet_1_of_2.SLDDRW
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

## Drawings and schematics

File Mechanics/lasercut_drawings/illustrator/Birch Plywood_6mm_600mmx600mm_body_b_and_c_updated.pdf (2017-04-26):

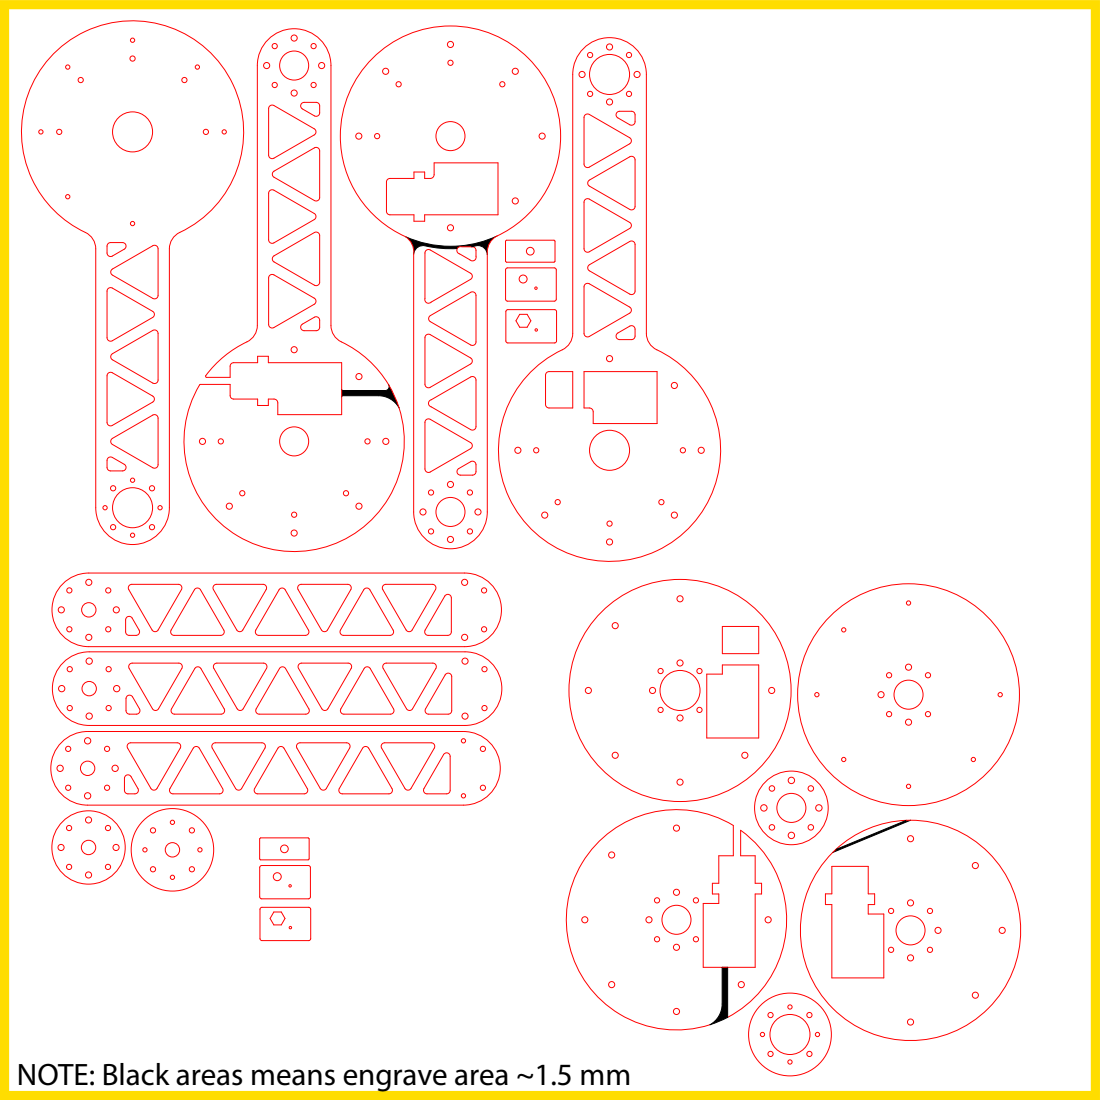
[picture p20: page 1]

NOTE: Black areas means engrave area ~1.5 mm

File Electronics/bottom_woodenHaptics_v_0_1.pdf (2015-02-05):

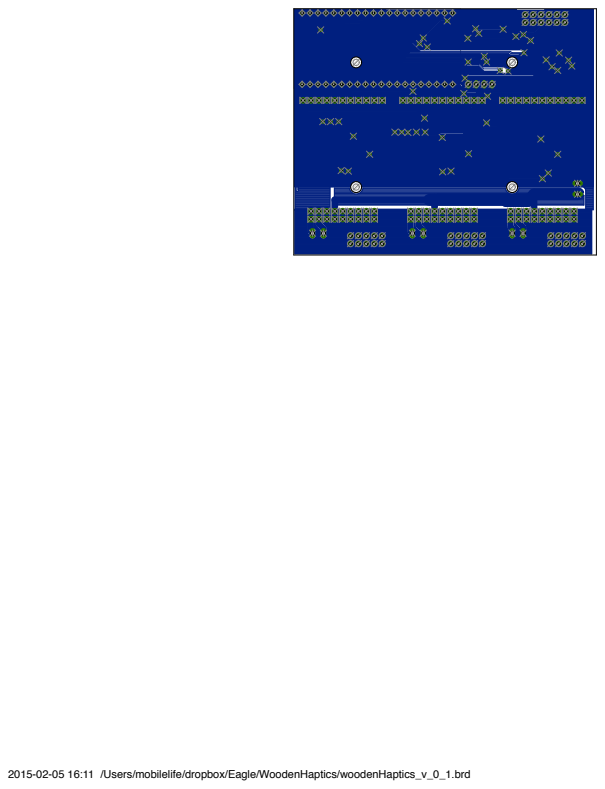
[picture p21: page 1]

2015-02-05 16:11 /Users/mobilelife/dropbox/Eagle/WoodenHaptics/woodenHaptics_v_0_1.brd

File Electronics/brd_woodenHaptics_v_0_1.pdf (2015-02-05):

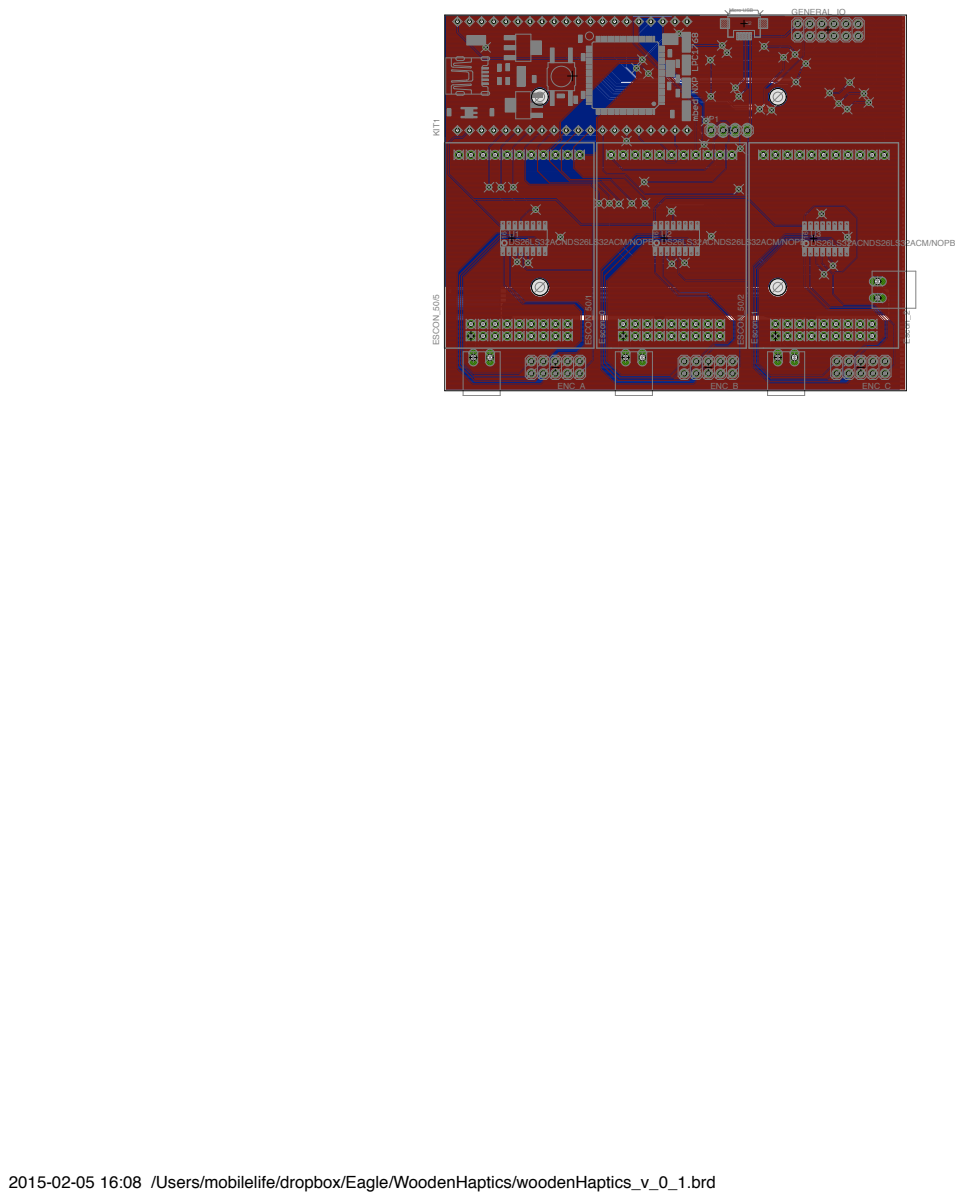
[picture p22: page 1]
2015-02-05 16:08 /Users/mobilelife/dropbox/Eagle/WoodenHaptics/woodenHaptics_v_0_1.brd ¹⁶; ENC_A; ENC_B; ENC_C; KIT1; GENERAL_IO; ESCON_50/5; ESCON_50/1; ESCON_50/2; Escon_0; Escon_1; Escon_2; Micro USB

DS26LS32ACNDS26LS32ACM/NOPB DS26LS32ACNDS26LS32ACM/NOPB DS26LS32ACNDS26LS32ACM/NOPB

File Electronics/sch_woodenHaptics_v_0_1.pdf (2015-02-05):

2015-02-05 16:07 /Users/mobilelife/dropbox/Eagle/WoodenHaptics/woodenHaptics_v_0_1.sch (Sheet: 1/1) V⁺

19 | P$19 20 | P$20 21 | P$21 22 | P$22 23 | P$23 24 | P$24 25 | P$25 26 | P$26 27 | P$27 28 | P$28 29 | P$29

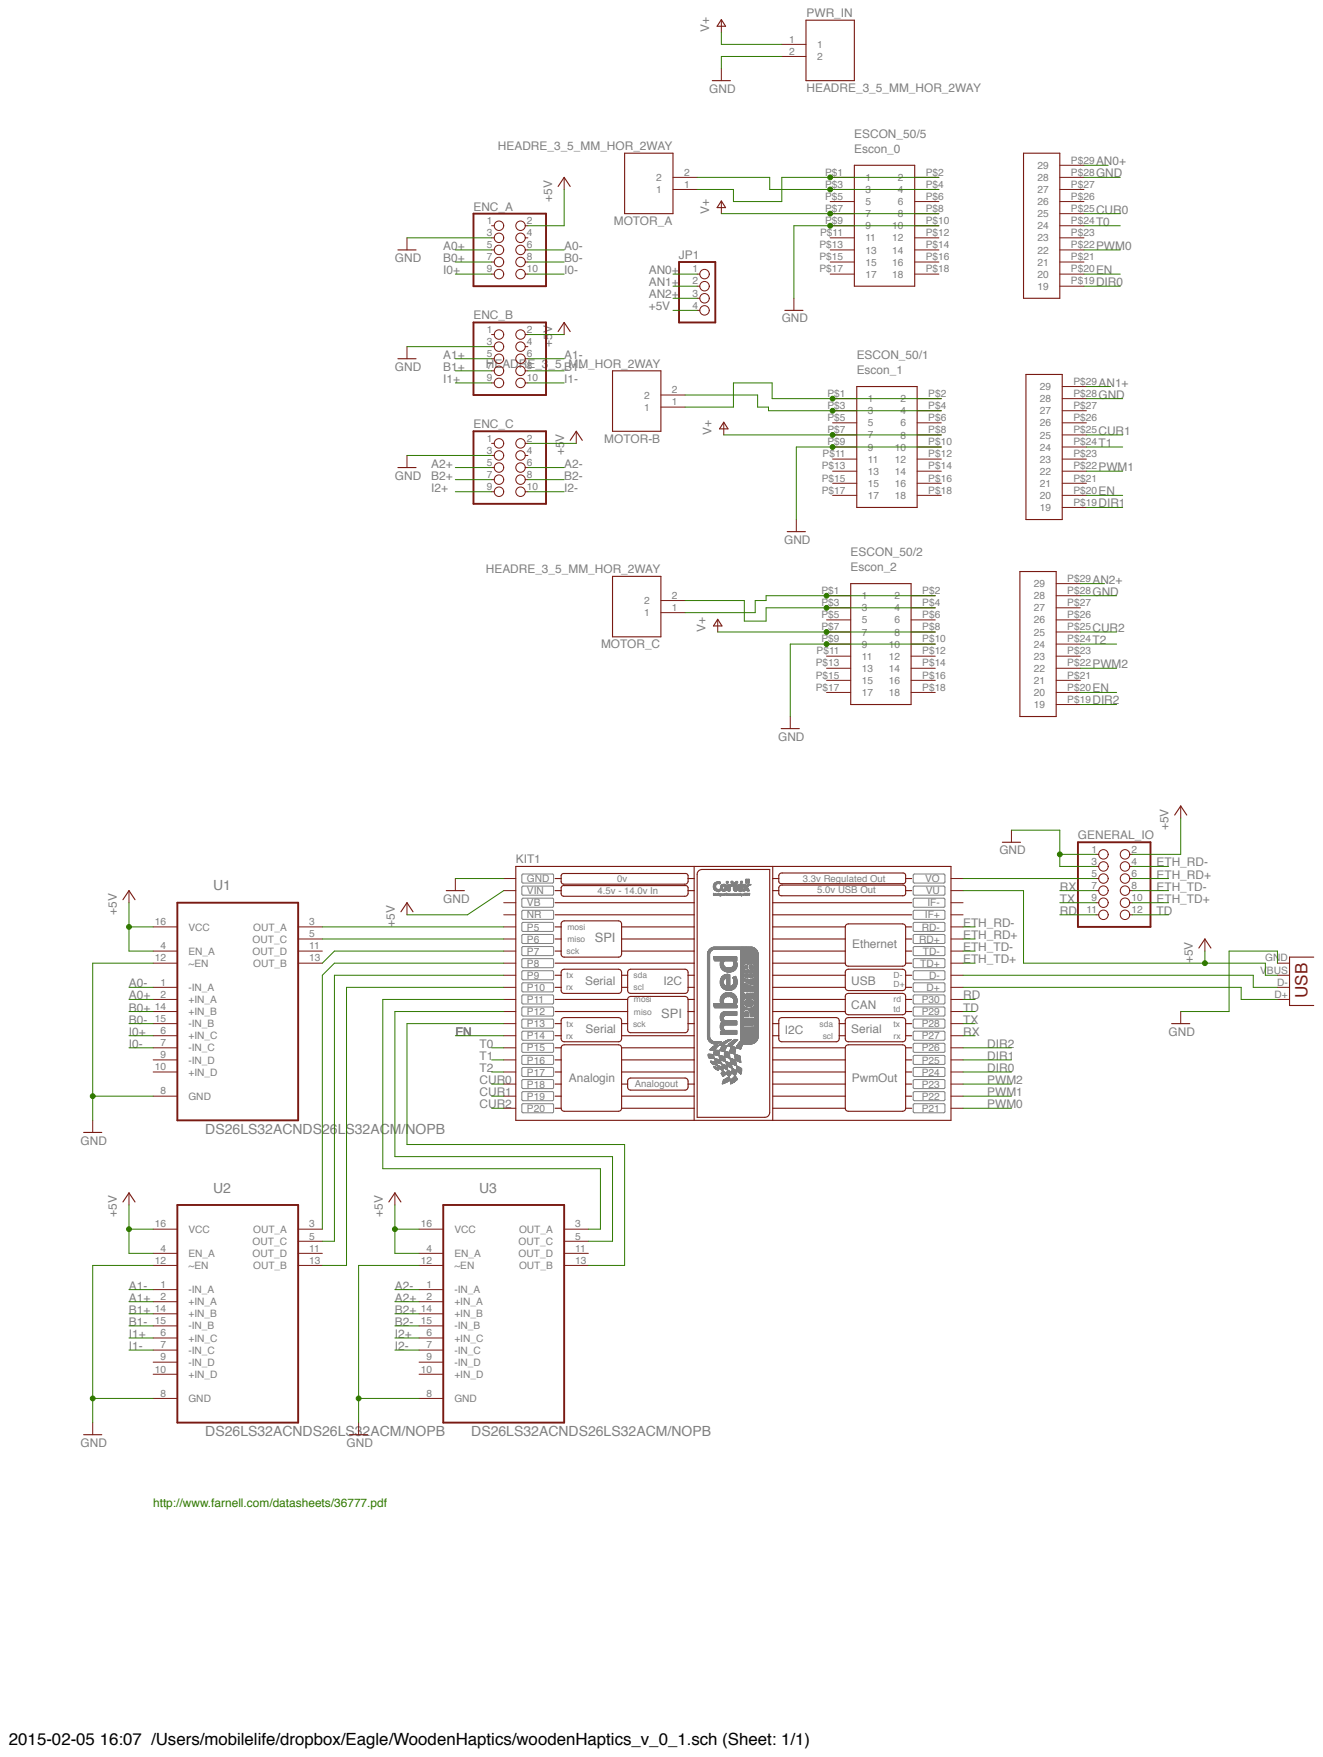
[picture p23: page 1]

http://www.farnell.com/datasheets/36777.pdf

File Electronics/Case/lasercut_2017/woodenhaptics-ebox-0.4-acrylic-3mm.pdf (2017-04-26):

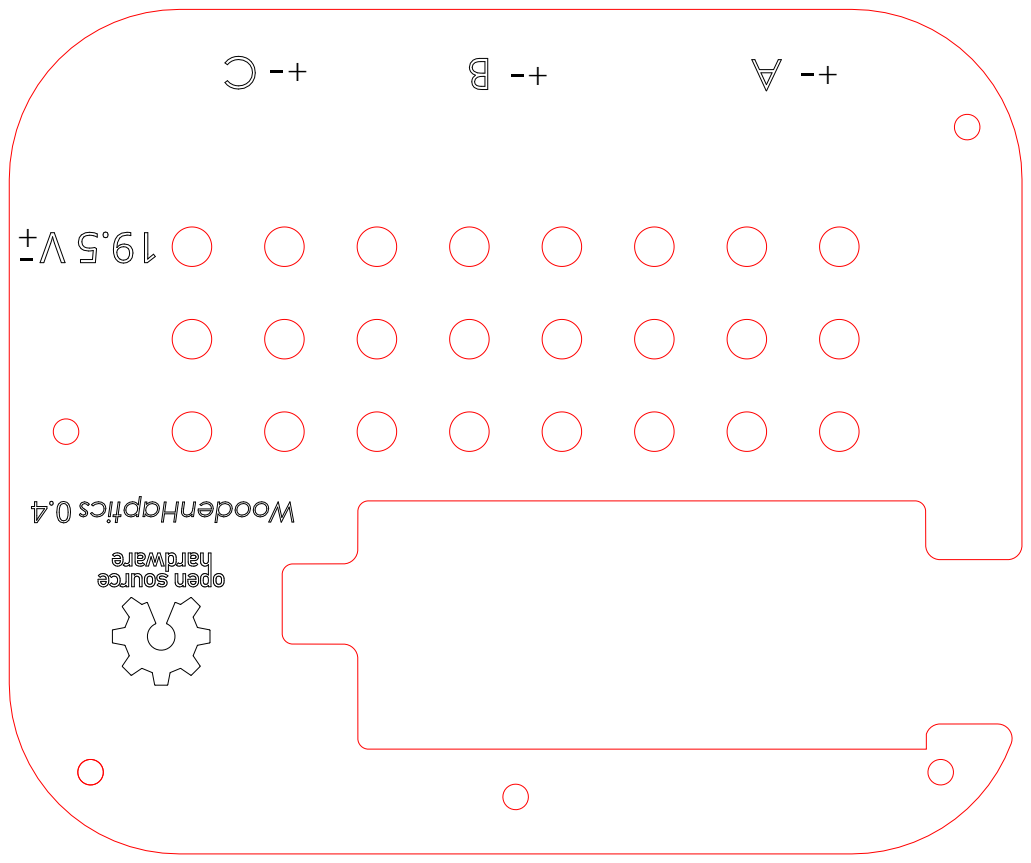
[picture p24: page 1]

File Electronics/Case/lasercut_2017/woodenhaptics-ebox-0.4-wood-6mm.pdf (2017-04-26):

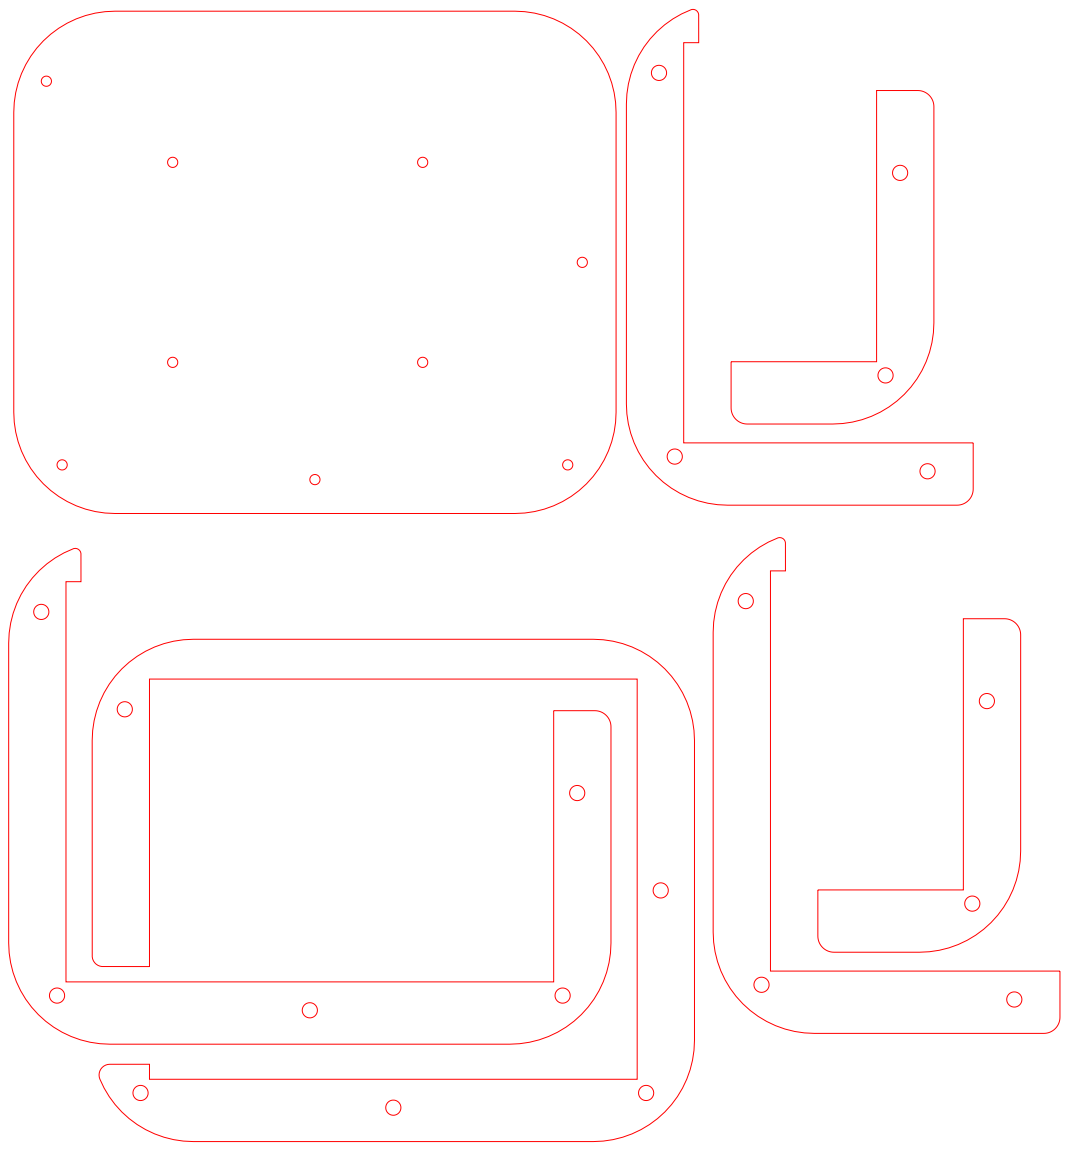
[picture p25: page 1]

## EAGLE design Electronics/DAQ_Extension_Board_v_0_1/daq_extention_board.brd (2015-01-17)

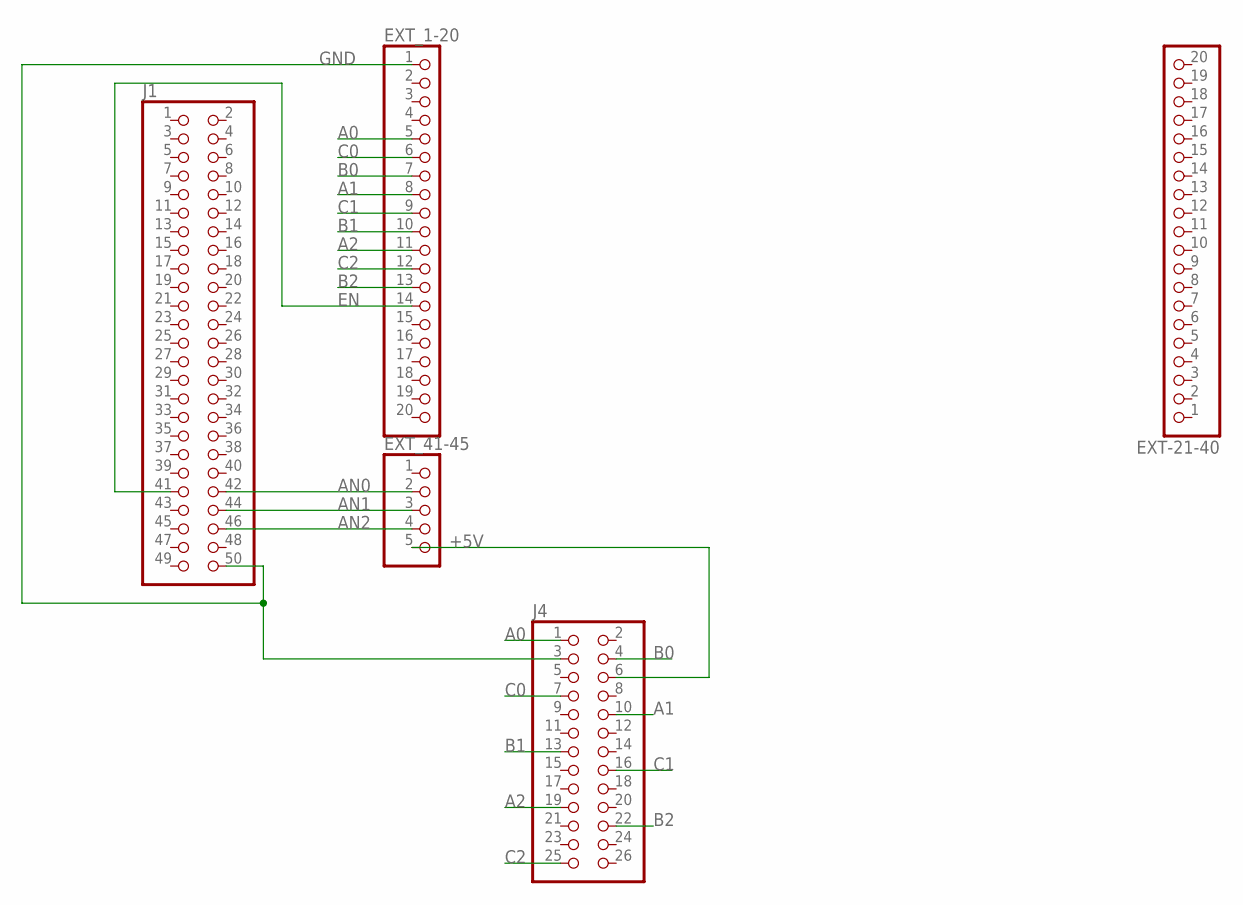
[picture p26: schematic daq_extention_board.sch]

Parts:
EXT-21-40: PINHD-1X20; 1X20
EXT_1-20: PINHD-1X20; 1X20
EXT_41-45: PINHD-1X5; 1X05
J1: PINHD-2X25; 2X25
J4: PINHD-2X13; 2X13

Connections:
+5V: EXT_41-45.5, J4.6
A0: EXT_1-20.5, J4.1
A1: EXT_1-20.8, J4.10
A2: EXT_1-20.11, J4.19
AN0: EXT_41-45.2, J1.42
AN1: EXT_41-45.3, J1.44
AN2: EXT_41-45.4, J1.46
B0: EXT_1-20.7, J4.4
B1: EXT_1-20.10, J4.13
B2: EXT_1-20.13, J4.22
C0: EXT_1-20.6, J4.7
C1: EXT_1-20.9, J4.16
C2: EXT_1-20.12, J4.25
EN: EXT_1-20.14, J1.41
GND: EXT_1-20.1, J1.50, J4.3

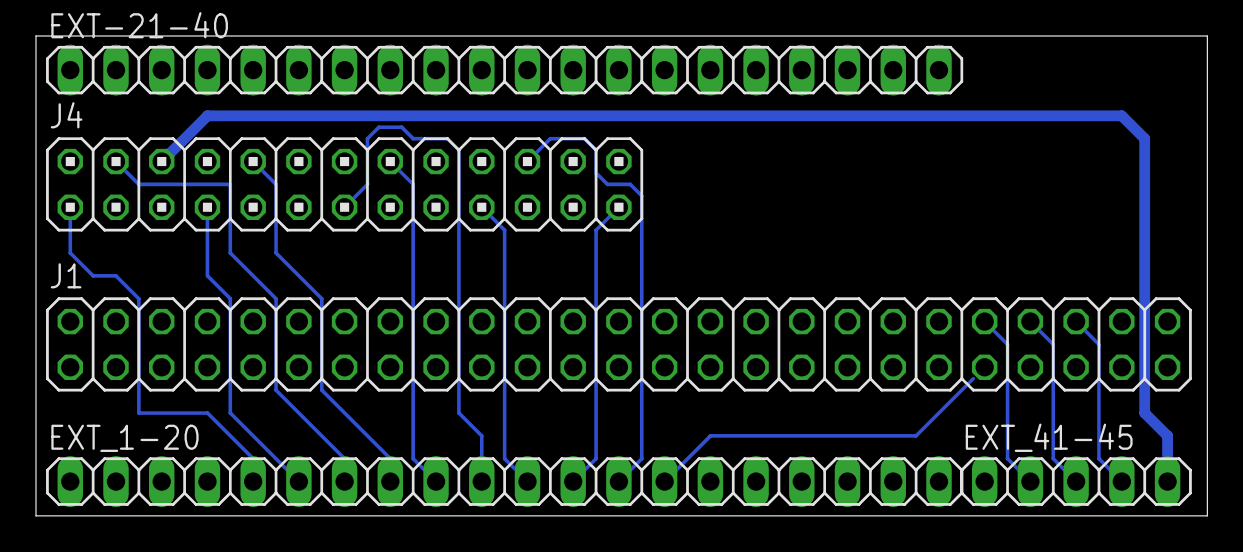
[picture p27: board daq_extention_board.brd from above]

Board: 2 copper layers, 65.1 x 26.7 mm, 5 parts (0 on the bottom side), 15 nets.

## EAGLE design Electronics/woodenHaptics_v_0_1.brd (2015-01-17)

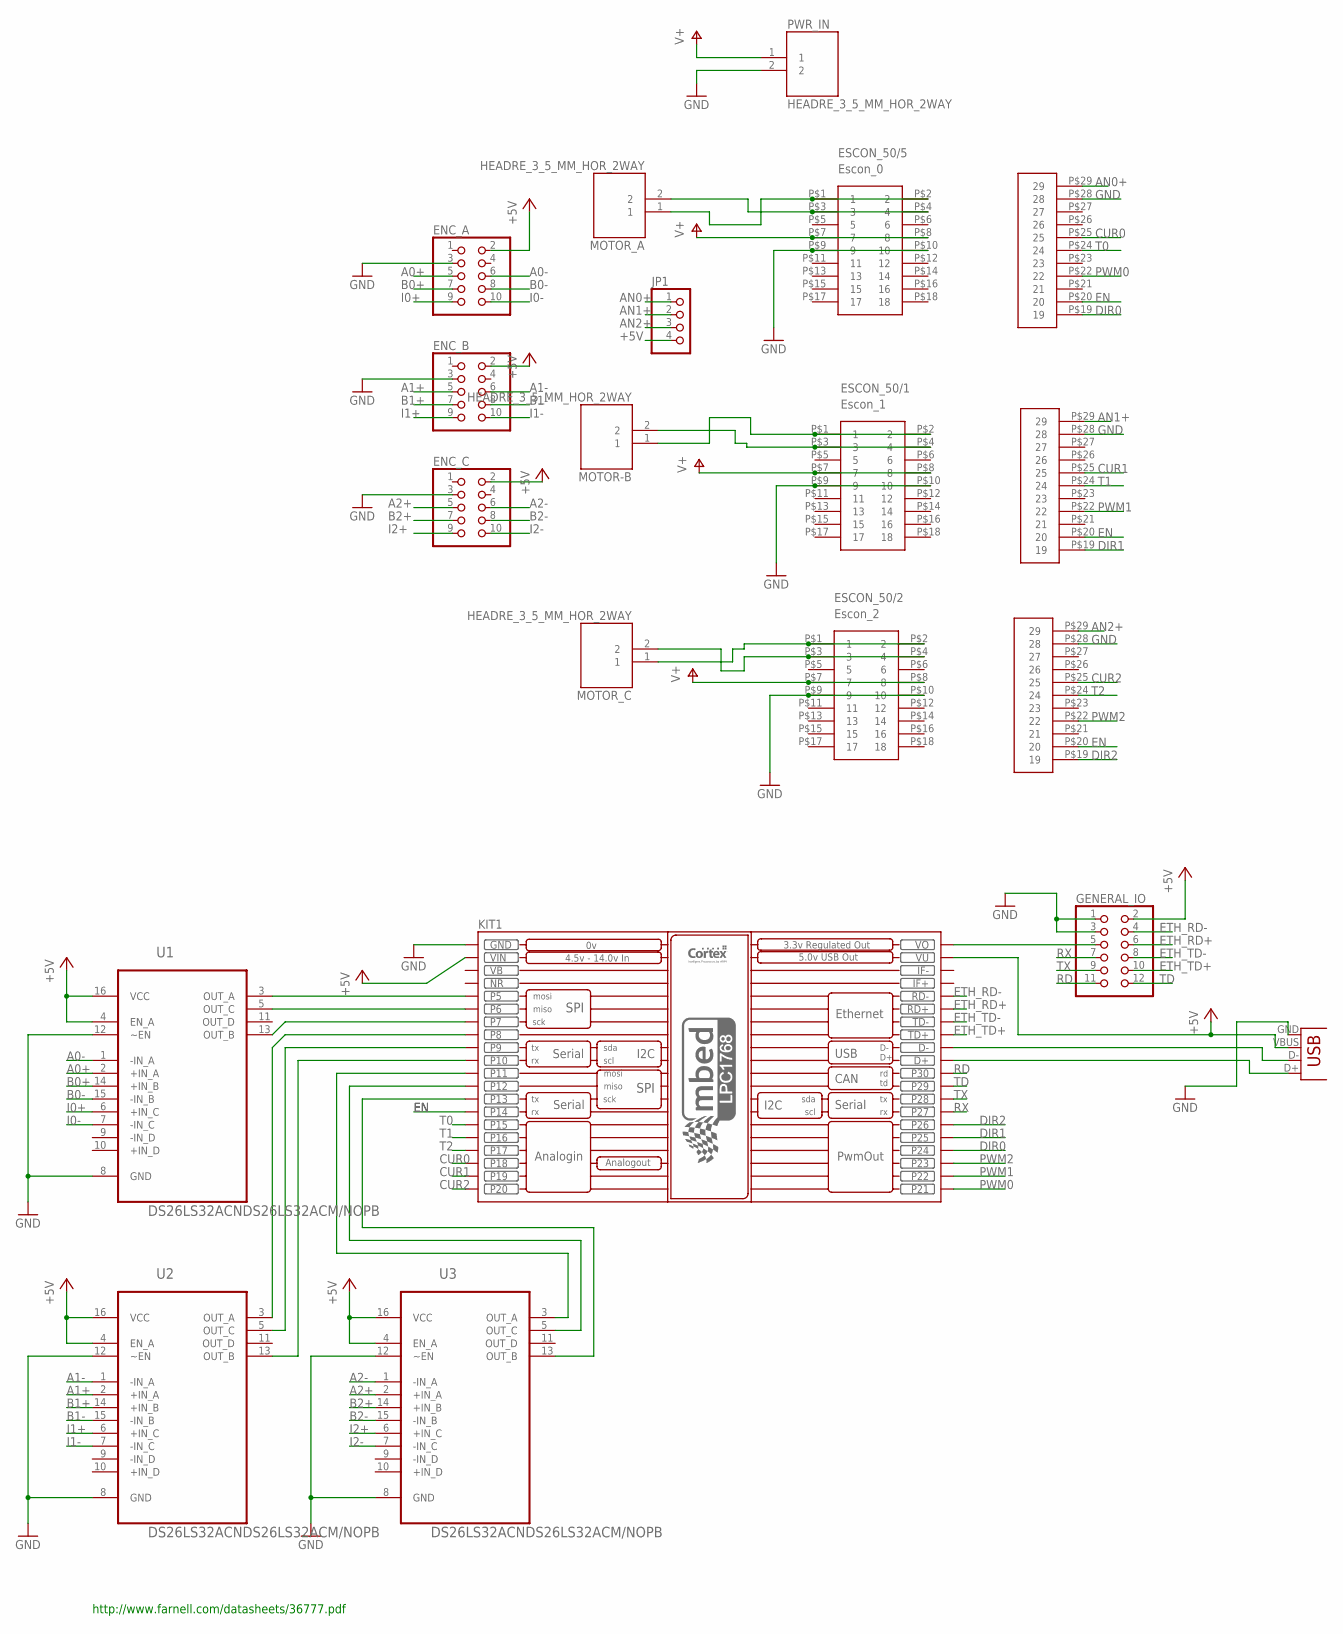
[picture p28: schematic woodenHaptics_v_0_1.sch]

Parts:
ENC_A: PINHD-2X5; 2X05
ENC_B: PINHD-2X5; 2X05
ENC_C: PINHD-2X5; 2X05
ESCON_50/1: Escon_1; MODULE
ESCON_50/2: Escon_2; MODULE
ESCON_50/5: Escon_0; MODULE
GENERAL_IO: PINHD-2X6; 2X06
JP1: PINHD-1X4; 1X04
KIT1: MBED_NXP_LPC1768; MBED-KIT
MOTOR-B: HEADRE_3_5_MM_HOR_2WAY; HEADER_3_5MM_HOR_2WAY
MOTOR_A: HEADRE_3_5_MM_HOR_2WAY; HEADER_3_5MM_HOR_2WAY
MOTOR_C: HEADRE_3_5_MM_HOR_2WAY; HEADER_3_5MM_HOR_2WAY
PWR_IN: HEADRE_3_5_MM_HOR_2WAY; HEADER_3_5MM_HOR_2WAY
U1, U2, U3: DS26LS32ACNDS26LS32ACM/NOPB; M16
X2: Micro USB; USB-MICROB

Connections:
+5V: ENC_A.2, ENC_B.2, ENC_C.2, GENERAL_IO.2, JP1.4, KIT1.VIN, KIT1.VU, U1.4 (EN_A), U1.16 (VCC), U2.4 (EN_A), U2.16 (VCC), U3.4 (EN_A), U3.16 (VCC), X2.VBUS
A0+: ENC_A.5, U1.2 (+IN_A)
A0-: ENC_A.6, U1.1 (-IN_A)
A1+: ENC_B.5, U2.2 (+IN_A)
A1-: ENC_B.6, U2.1 (-IN_A)
A2+: ENC_C.5, U3.2 (+IN_A)
A2-: ENC_C.6, U3.1 (-IN_A)
AN0+: ESCON_50/5.P$29 (29), JP1.1
AN1+: ESCON_50/1.P$29 (29), JP1.2
AN2+: ESCON_50/2.P$29 (29), JP1.3
B0+: ENC_A.7, U1.14 (+IN_B)
B0-: ENC_A.8, U1.15 (-IN_B)
B1+: ENC_B.7, U2.14 (+IN_B)
B1-: ENC_B.8, U2.15 (-IN_B)
B2+: ENC_C.7, U3.14 (+IN_B)
B2-: ENC_C.8, U3.15 (-IN_B)
CUR0: ESCON_50/5.P$25 (25), KIT1.P$18 (P18)
CUR1: ESCON_50/1.P$25 (25), KIT1.P$19 (P19)
CUR2: ESCON_50/2.P$25 (25), KIT1.P$20 (P20)
DIR0: ESCON_50/5.P$19 (19), KIT1.P$24 (P24)
DIR1: ESCON_50/1.P$19 (19), KIT1.P$25 (P25)
DIR2: ESCON_50/2.P$19 (19), KIT1.P$26 (P26)
EN: ESCON_50/1.P$20 (20), ESCON_50/2.P$20 (20), ESCON_50/5.P$20 (20), KIT1.P$14 (P14)
ETH_RD+: GENERAL_IO.6, KIT1.RD+
ETH_RD-: GENERAL_IO.4, KIT1.RD-
ETH_TD+: GENERAL_IO.10, KIT1.TD+
ETH_TD-: GENERAL_IO.8, KIT1.TD-
GND: ENC_A.3, ENC_B.3, ENC_C.3, ESCON_50/1.P$9 (9), ESCON_50/1.P$10 (10), ESCON_50/1.P$28 (28), ESCON_50/2.P$9 (9), ESCON_50/2.P$10 (10), ESCON_50/2.P$28 (28), ESCON_50/5.P$9 (9), ESCON_50/5.P$10 (10), ESCON_50/5.P$28 (28), GENERAL_IO.1, GENERAL_IO.3, KIT1.GND, PWR_IN.2, U1.8 (GND), U1.12 (~EN), U2.8 (GND), U2.12 (~EN), U3.8 (GND), U3.12 (~EN), X2.GND
I0+: ENC_A.9, U1.6 (+IN_C)
I0-: ENC_A.10, U1.7 (-IN_C)
I1+: ENC_B.9, U2.6 (+IN_C)
I1-: ENC_B.10, U2.7 (-IN_C)
I2+: ENC_C.9, U3.6 (+IN_C)
I2-: ENC_C.10, U3.7 (-IN_C)
unnamed: ESCON_50/5.P$3 (3), ESCON_50/5.P$4 (4), MOTOR_A.2
unnamed: ESCON_50/1.P$1 (1), ESCON_50/1.P$2 (2), MOTOR-B.1
unnamed: KIT1.D-, X2.D-
unnamed: ESCON_50/1.P$3 (3), ESCON_50/1.P$4 (4), MOTOR-B.2
unnamed: ESCON_50/2.P$1 (1), ESCON_50/2.P$2 (2), MOTOR_C.1
unnamed: ESCON_50/2.P$3 (3), ESCON_50/2.P$4 (4), MOTOR_C.2
unnamed: KIT1.D+, X2.D+
unnamed: KIT1.P$8 (P8), U2.3 (OUT_A)
unnamed: GENERAL_IO.5, KIT1.VOUT (VO)
unnamed: KIT1.P$5 (P5), U1.3 (OUT_A)
unnamed: KIT1.P$6 (P6), U1.5 (OUT_C)
unnamed: KIT1.P$7 (P7), U1.13 (OUT_B)
unnamed: KIT1.P$9 (P9), U2.5 (OUT_C)
unnamed: KIT1.P$10 (P10), U2.13 (OUT_B)
unnamed: KIT1.P$11 (P11), U3.3 (OUT_A)
unnamed: KIT1.P$12 (P12), U3.5 (OUT_C)
unnamed: KIT1.P$13 (P13), U3.13 (OUT_B)
unnamed: ESCON_50/5.P$1 (1), ESCON_50/5.P$2 (2), MOTOR_A.1
NR: KIT1.NR
PWM0: ESCON_50/5.P$22 (22), KIT1.P$21 (P21)
PWM1: ESCON_50/1.P$22 (22), KIT1.P$22 (P22)
PWM2: ESCON_50/2.P$22 (22), KIT1.P$23 (P23)
RD: GENERAL_IO.11, KIT1.P$30 (P30)
RX: GENERAL_IO.7, KIT1.P$27 (P27)
T0: ESCON_50/5.P$24 (24), KIT1.P$15 (P15)
T1: ESCON_50/1.P$24 (24), KIT1.P$16 (P16)
T2: ESCON_50/2.P$24 (24), KIT1.P$17 (P17)
TD: GENERAL_IO.12, KIT1.P$29 (P29)
TX: GENERAL_IO.9, KIT1.P$28 (P28)
V+: ESCON_50/1.P$7 (7), ESCON_50/1.P$8 (8), ESCON_50/2.P$7 (7), ESCON_50/2.P$8 (8), ESCON_50/5.P$7 (7), ESCON_50/5.P$8 (8), PWR_IN.1
VB: KIT1.VB

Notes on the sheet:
http://www.farnell.com/datasheets/36777.pdf

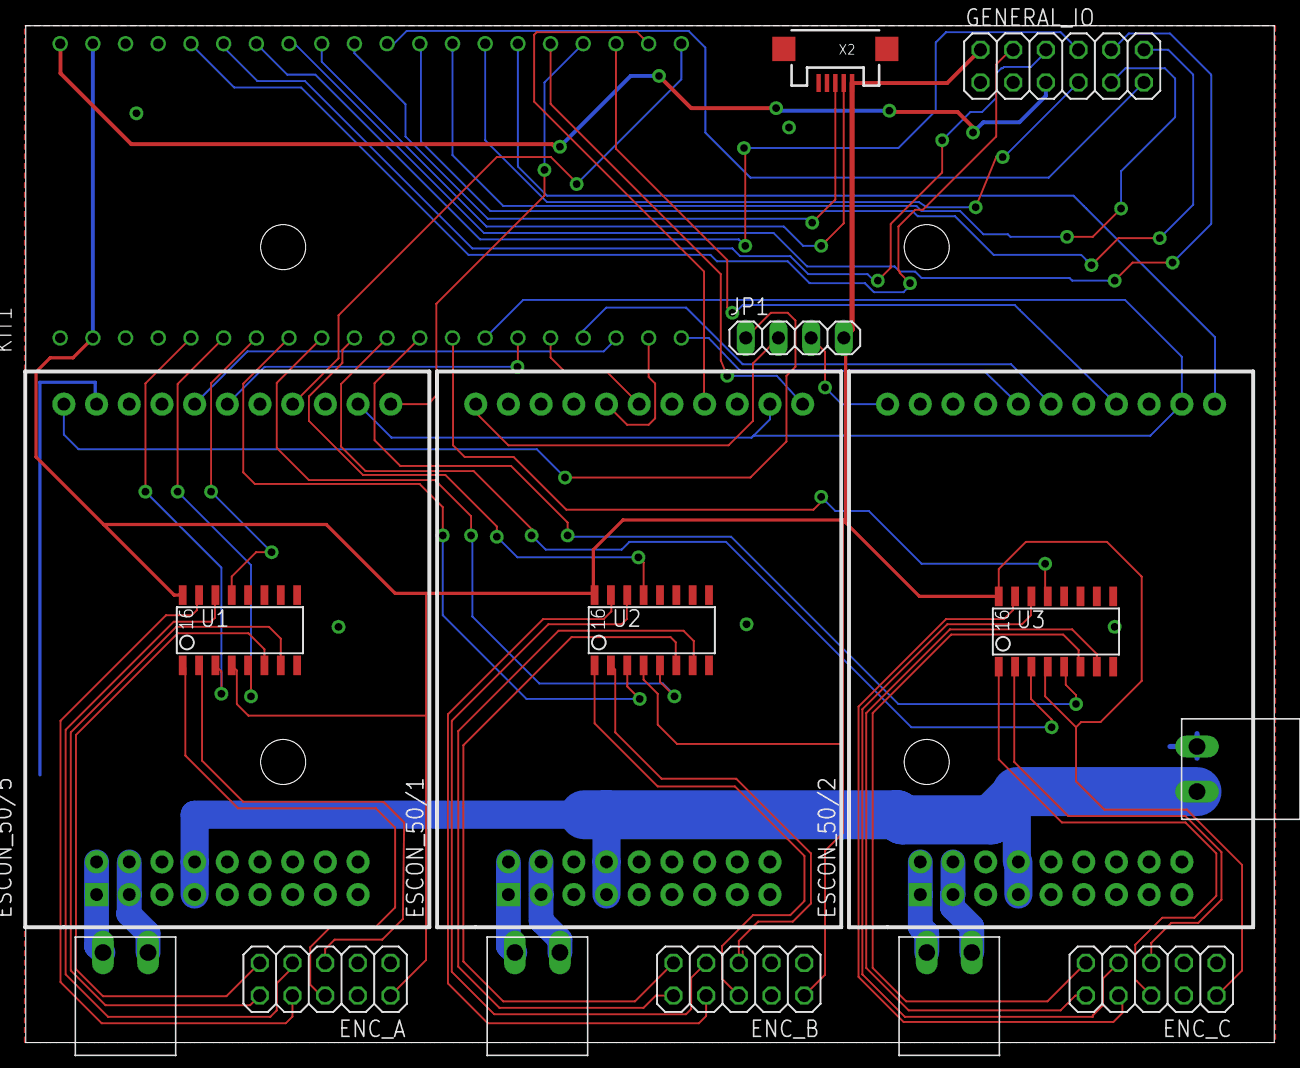
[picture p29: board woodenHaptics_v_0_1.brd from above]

Board: 2 copper layers, 97.0 x 79.0 mm, 17 parts (0 on the bottom side), 63 nets.

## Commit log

2015-01-17 first commit
    first commit
    [RE40-148866.SLDPRT, base_10x22x6_bearing_Misumi_SB6900ZZ.SLDPRT, base_10x55x4x5_capstan.SLDPRT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]
2015-01-17 Software, electronics case etc
    [base_assembly.SLDASM, board_outer_dimensions.SLDPRT, box.SLDASM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]
2015-01-23 vent holes (and text) added to electronics case
    [box.SLDASM, box_5_acrylic.SLDPRT, electronics_box_3-6mm_A4_acrylic_or_plywood_2_of_2.DXF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]
2015-05-26 reference order pcb
2015-06-02 Added illustrator lasercut files
2017-03-08 added encoder doc
2017-04-26 lasercut box 2017 (version 0.4)
2019-05-18 bom archived
    [WoodenHaptics Bill of Materials - Version 1.0 TEI-2015 Edition.csv]
2026-05-19 Add FreeCAD migration plan
    Outlines steps to publish an articulated open-source FreeCAD version
    of the device: per-subassembly STEP exports from Onshape, five rigid
    subassembly documents, and a top-level assembly with revolute joints
    for θa/θb/θc plus the C/C' parallelogram closure.
2026-05-19 Add TEI 2015 paper PDF
    Forsslund, Yip, Sallnäs — WoodenHaptics: A Starting Kit for Crafting
    Force-Reflecting Spatial Haptic Devices. TEI 2015.
2026-06-11 Add 2017 Edition (lasercut + BOM v1.1, RE30) and provenance README
    Retroactively gathers the never-released 2017 revision: the lightened
    arm laser files, the as-built A2 four-sheet production cut, intermediate
    re-nests, and BOM v1.1 (30 mm motors + USB). README documents a
    source-verified timeline, the RE40->RE30 changes, and gaps (the arm CAD
    is Onshape-only). Editions kept as a folder, not a branch.
    [WoodenHaptics Bill of Materials - 2017 Edition (Ver 1.1 with 30mm motors and USB).csv]
2026-06-11 Add 2026 consolidation plan
    Handoff doc for gathering all WoodenHaptics material into a single
    canonical 2026 repo. Surveys the GitHub landscape (TEI_2015,
    woody-experimental, the stale forsslund fork), lays out the open
    org-vs-personal home decision with a recommendation, proposes an
    edition-folder structure, and records which local files are safe to
    drop so work can resume from another machine.
